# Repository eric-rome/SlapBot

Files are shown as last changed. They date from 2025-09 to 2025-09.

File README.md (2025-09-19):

# SlapBot

SlapBot és un robot físic capaç de jugar al joc de cartes **El Tapete** de manera autònoma.  
Combina visió per computador, control de motors i sensors per reconèixer cartes, prendre decisions i competir contra jugadors humans en temps real.

---

## 🧠 Descripció general

El robot es compon de quatre mòduls principals:

- **Mecanisme de "slap"**: braç que colpeja la taula quan detecta una combinació guanyadora.
- **Llença-cartes**: mecanisme que permet al robot descartar cartes durant la partida.
- **Sistema de visió**: càmera connectada a una Raspberry Pi que reconeix les cartes jugades mitjançant un model de Roboflow.
- **Sensors de detecció de guanyador**: dos sensors d’ultrasons que detecten qui ha picat primer a la taula.

El reconeixement de cartes es fa mitjançant una **API de Roboflow**, integrada al codi de `src/raspberry_pi4`, que processa les imatges captades per la càmera i retorna el valor de la carta al programa principal.  
Inicialment s’havia creat una xarxa neuronal pròpia (`src/neural_network`), però tot i obtenir una bona precisió en entrenament (>0.9), no donava resultats fiables en temps real, per la qual cosa es va optar per utilitzar Roboflow.

---

## 🎥 Vídeo de demostració

Veure vídeo (https://youtu.be/LgzfWQ4xZNc)

---

## ⚙️ Tecnologies utilitzades

**Software**
- Python 3 (Raspberry Pi 4)
- C++ (Arduino Nano)

**API**
- Projecte de Roboflow per a detecció de cartes  
  (vegeu `src/raspberry_pi4/execute_program_and_cite_project_api_roboflow`)

**Hardware**
- Raspberry Pi 4  
- Càmera Eye PlayStation 3  
- Arduino Nano  
- 2 sensors d’ultrasons HC-SR04  
- Motor DC i mini motor DC  
- Controladora TB6612FNG per a motors  
- Altaveu  
- Font d’alimentació de 6 piles (7,2 V a 9 V)

---

## 🧩 Arquitectura

**Esquema de hardware**

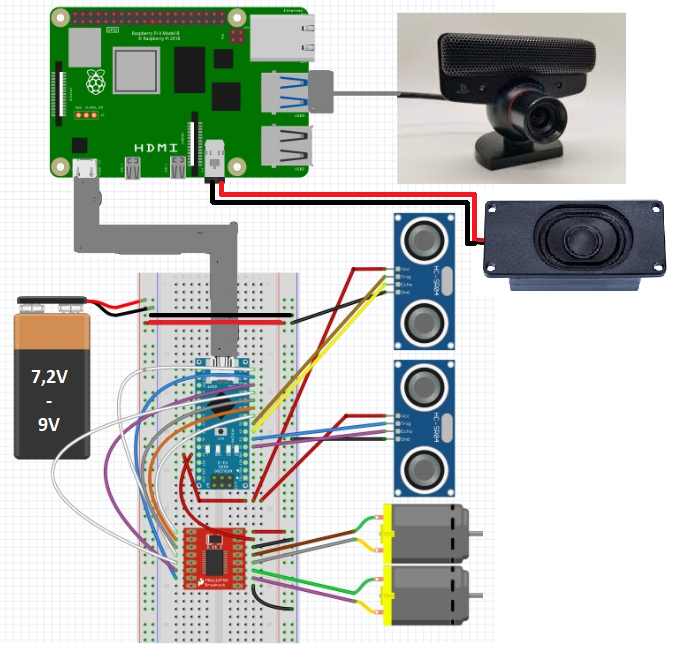
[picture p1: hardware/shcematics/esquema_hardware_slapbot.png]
Esquema de hardware


**Diagrama de software**

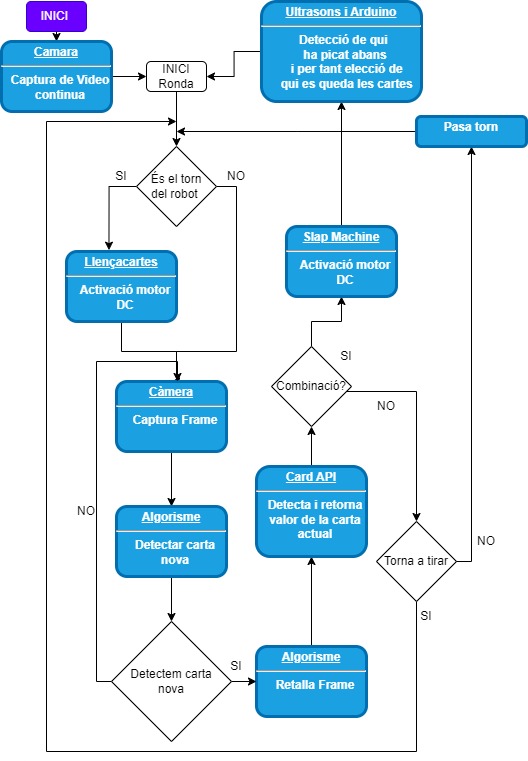
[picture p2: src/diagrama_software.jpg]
Diagrama de software


---

## 📁 Estructura del codi

- **`src/arduino`**  
  Controla els sensors i motors. L’Arduino detecta qui pica primer a la taula (robot o jugadors humans) i envia aquesta informació a la Raspberry Pi. També activa el mecanisme del braç i el llença-cartes quan cal.

- **`src/neural_network`**  
  Conté el codi i el model entrenat per al reconeixement de cartes mitjançant xarxes neuronals. Finalment no es va utilitzar en el sistema final, però s’inclou com a referència i documentació del procés.

- **`src/raspberry_pi4`**  
  Implementa el programa principal, la gestió de torns i la comunicació amb l’Arduino, la càmera i l’API de Roboflow. Inclou instruccions d’execució al fitxer `explicacio.md`.

---

## 🃏 Funcionament del joc

- La partida comença sempre amb el robot per sincronitzar el sistema.  
- Durant el seu torn, el robot llença una carta. Si ha de jugar més d’una, espera a detectar l’última carta llençada abans de continuar.  
- Durant el torn dels jugadors humans, el robot reconeix les cartes jugades amb la càmera i el sistema de visió.  
- Seguint les normes d’**El Tapete**, el robot pica a la taula quan detecta:
  - dues cartes consecutives del mateix valor
  - un “sandvitx” (dues cartes iguals separades per una diferent)
- Els jugadors han de picar entre el sensor i la pila de cartes; si ho fan abans que el robot, se’n porten les cartes.
- Després de cada ronda, si el robot guanya, s’ha de **recarregar el dispensador de cartes manualment** durant una pausa de 20 segons.
- El jugador que acabi amb totes les cartes és el guanyador.

---

## 👥 Autors

- Pol Reyes Martí  
- Eric Rodríguez Merichal 
- Valentí Torrents Vila 
- Guillermo Vivancos Alonso

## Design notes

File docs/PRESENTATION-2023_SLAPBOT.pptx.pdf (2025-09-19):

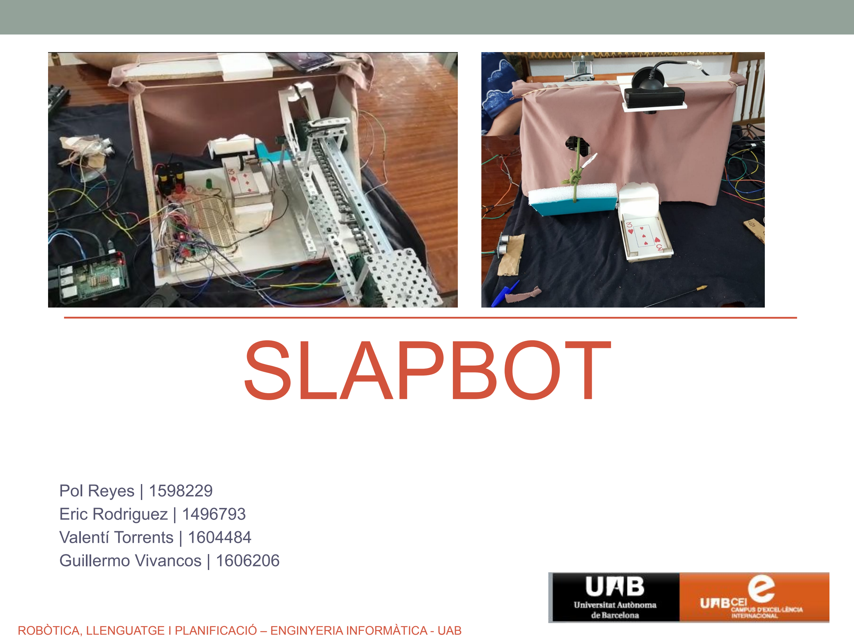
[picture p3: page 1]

# SLAPBOT

Pol Reyes | 1598229
Eric Rodriguez | 1496793
Valentí Torrents | 1604484
Guillermo Vivancos | 1606206

ROBÒTICA, LLENGUATGE I PLANIFICACIÓ – ENGINYERIA INFORMÀTICA - UAB

# 1. Arquitectura hardware i software

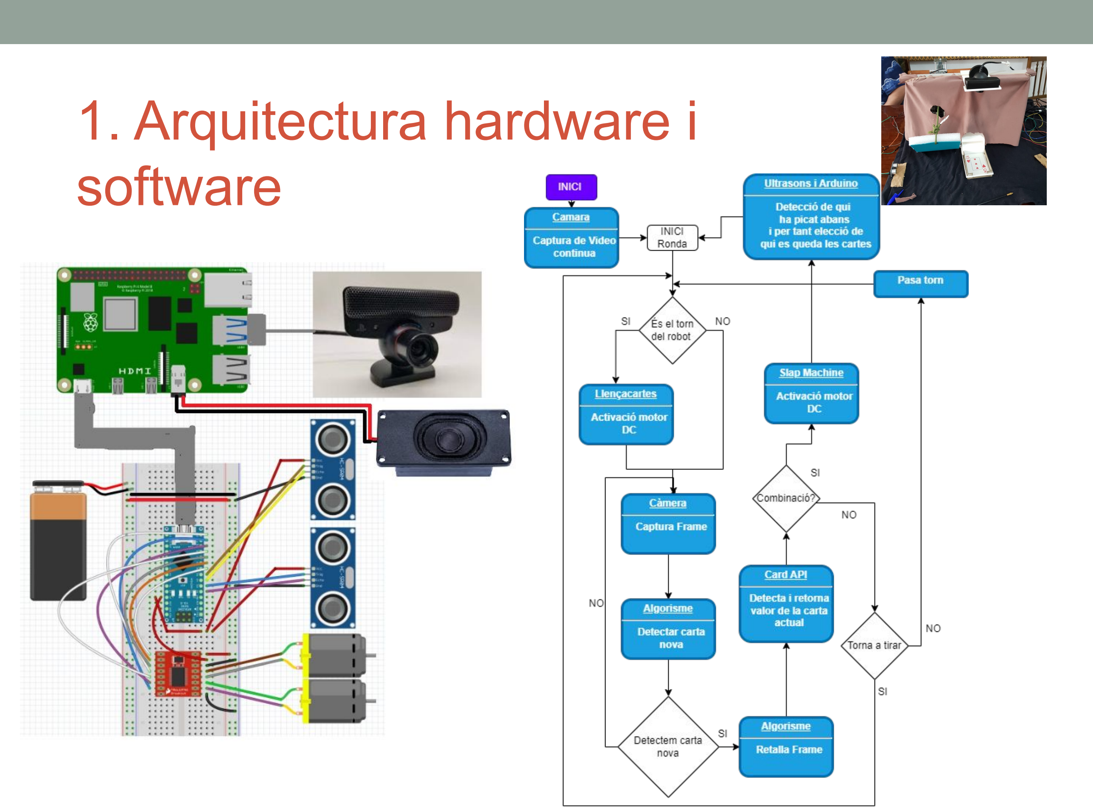
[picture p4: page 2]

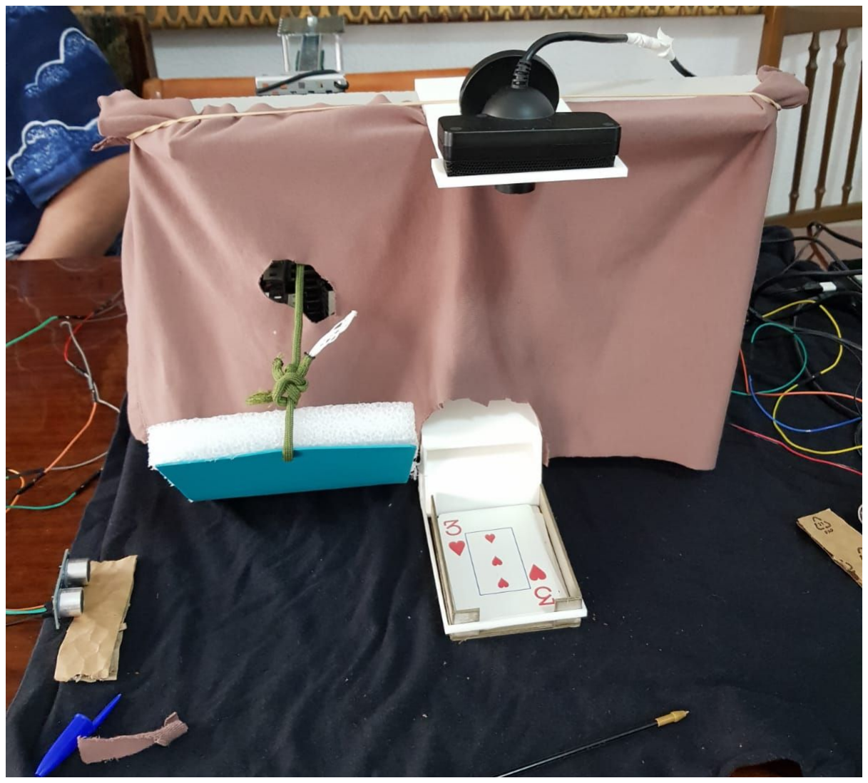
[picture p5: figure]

# 2. Algorísmica

Visió per Computador:
- Xarxa Neuronal per detecció de cartes.
- Retallar frames per evitar el màxim soroll possible.
- Comparació constant de frames.

API:
- Roboflow per a detecció de cartes.

Algorisme:
- Algorisme que permet al robot jugar al “Tapete”.
- Utilitza tots els recursos del robot per jugar.

# FOTOS, VIDEO i Git

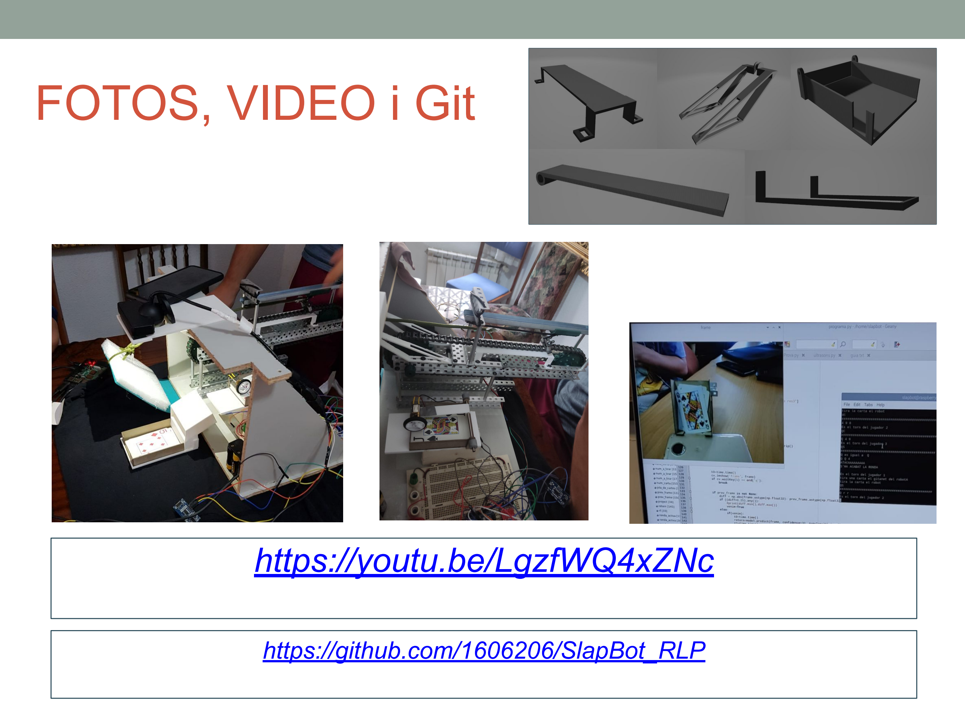
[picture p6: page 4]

## https://youtu.be/LgzfWQ4xZNc

https://github.com/1606206/SlapBot_RLP

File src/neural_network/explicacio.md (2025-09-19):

Tot i aconseguir un accuracy alt de train i un alt accuracy de test amb la BBDD, el passar-ho al programa no aconseguiem que encertes les cartes.
Així doncs, com es reflexa al programa de la raspberry pi s'ha decidit utilitzar l'api de roboflow utilitzant un model ja entrenat.

Així i tot, en aquesta carpeta es pot veure el codi per entrenar el model (.ipynb ja que s'ha utilitzat google colab per entrenar per la falta de recursos que teniem de cpu i gpu), la funció que es cridaria per obtenir la predicció i un exemple de com cridavem la funció utilitzant el model entrenat.

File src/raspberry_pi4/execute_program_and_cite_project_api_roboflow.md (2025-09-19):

# S'utilitza com API de Roboflow per a visió per computador un model ja entrenat.

# Crear un docker a la terminal de la raspberry pi:
curl -fsSL https://get.docker.com -o get-docker.sh
sudo sh get-docker.sh

# Terminal 1 executar les dues comandes següents:
### Comanda 1
sudo docker pull roboflow/inference-server:cpu
### Comanda 2
sudo docker run --net=host roboflow/inference-server:cpu

# Terminal 2 executar les dues comandes següents quan a terminal 1 surti que inference-server està llest per rebre tràfic:
### Comanda 1
python -m venv raspi
### Comanda 2
source raspi/bin/activate

A partir d'aquí executar el programa a la terminal 2 (si no està instal·lat roboflow fer: pip install roboflow al terminal 2):
python3 programa.py

# Citació a l'api de roboflow utilitzada; que al codi programa.py es crida:

@misc{ carddetpokerdeck_dataset,
    title = { carddetpokerdeck Dataset },
    type = { Open Source Dataset },
    author = { h },
    howpublished = { \url{ https://universe.roboflow.com/h-pv33i/carddetpokerdeck } },
    url = { https://universe.roboflow.com/h-pv33i/carddetpokerdeck },
    journal = { Roboflow Universe },
    publisher = { Roboflow },
    year = { 2023 },
    month = { may },
    note = { visited on 2023-06-05 },
}

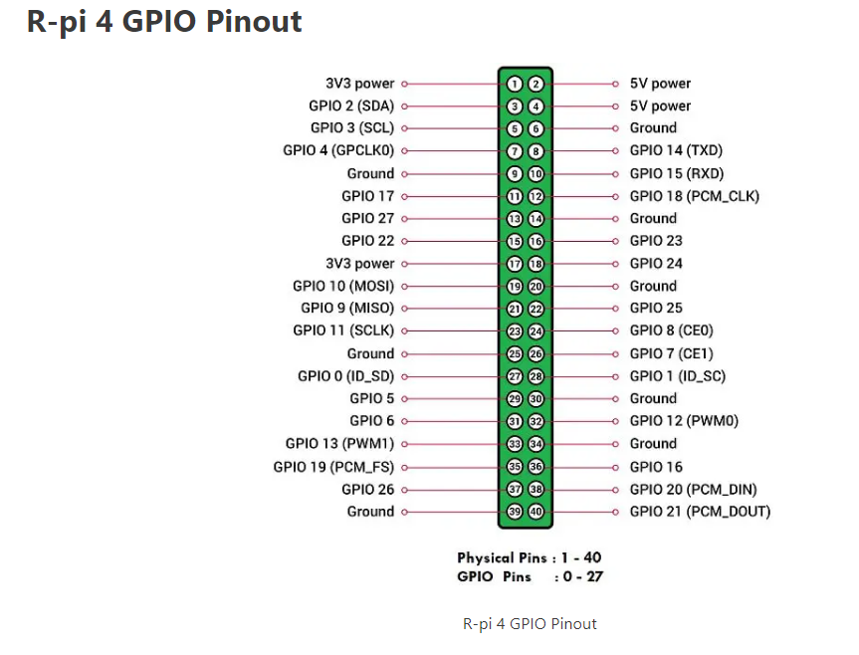
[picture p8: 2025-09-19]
hardware/shcematics/esquema_pi_4.PNG

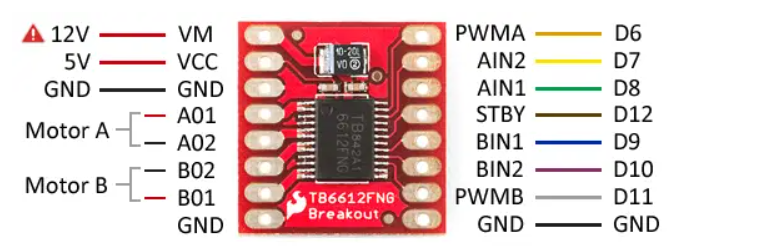
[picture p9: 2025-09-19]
hardware/shcematics/esquema_controladora.png

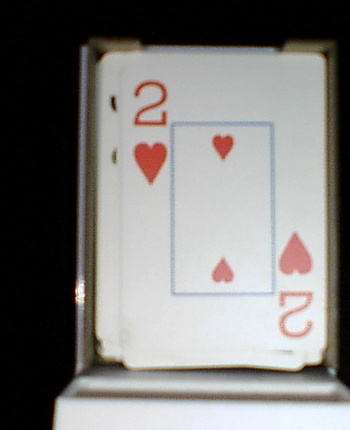
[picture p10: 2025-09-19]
src/neural_network/BBDD/2/2H.jpg

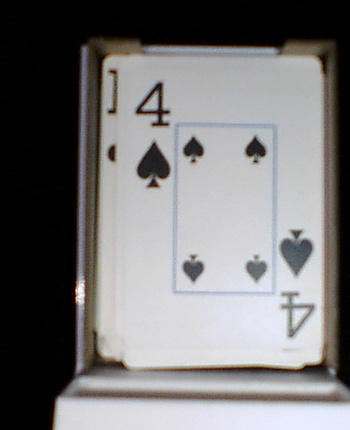
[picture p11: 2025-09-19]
src/neural_network/BBDD/4/4S.jpg

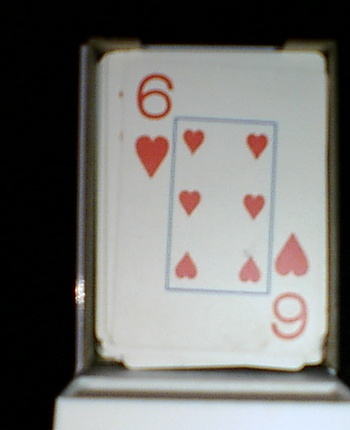
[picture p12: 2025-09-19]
src/neural_network/BBDD/6/6H.jpg

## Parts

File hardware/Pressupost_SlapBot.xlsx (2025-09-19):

Name | Price | Units | Total | URL
Mini motor DC | €3.03 | 1 | €3.03 | https://tienda.bricogeek.com/motores-dc/1606-mini-motor-dc-basico.html
Motor DC | €5.99 | 1 | €5.99 | https://www.vexrobotics.com/motors.html
Sensor ultrasonido | €2.18 | 2 | €4.36 | https://tienda.bricogeek.com/sensores-distancia/741-sensor-de-distancia-por-ultrasonidos-hc-sr04.html
Raspberry Pi 4 | €55.18 | 1 | €55.18 | https://www.raspipc.es/index.php?ver=tienda&accion=verArticulo&idProducto=1750
Arduino nano | €19.97 | 1 | €19.97 | https://tienda.bricogeek.com/arduino/305-arduino-uno.html
Cámara Playstation 3 | €19.00 | 1 | €19.00 | https://www.amazon.es/Sony-C%C3%A1mara-playstation-eye-ps3/dp/B000W3YQ1Y (https://tienda.bricogeek.com/sensores-imagen/1788-camara-hm0360-vga-para-raspberry-pi-pico.html)
Altavoz | €4.35 | 1 | €4.35 | https://tienda.bricogeek.com/varios/938-altavoz-con-caja-3w.html?search_query=speaker&results=3 (https://www.amazon.es/CQRobot-Speaker-Interface-Electronic-Projects/dp/B0822XCPT8?s=computers)
Fuente alimentación rasp | €9.92 | 1 | €9.92 | https://tienda.bricogeek.com/home/1331-fuente-alimentacion-raspberry-pi-4-usb-c-51v-3a.html
Fuente alimentación (petaca pilas) 9V | €1.45 | 1 | €1.45 | https://www.cablepelado.es/portapilas-para-6-pilas-lr6-aa-negro (https://tienda.bricogeek.com/kits-electronica-para-montar/81-kit-fuente-de-alimentacion-dc-5v-33v-para-placa-prototipo.html)
Controladora TB6612FNG | €9.95 | 1 | €9.95 | https://tienda.bricogeek.com/controladores-motores/999-controlador-de-motores-tb6612fng.html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 (https://satkit.com/es/l293d-arduino-shield-driver-control-expansion-para-control-m)
TOTAL |  |  | 133.20€

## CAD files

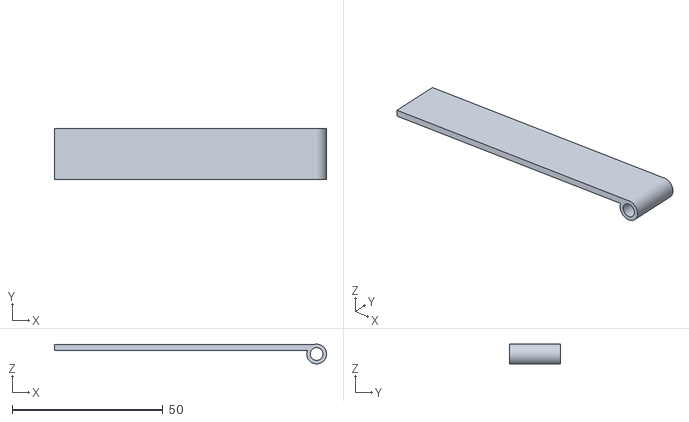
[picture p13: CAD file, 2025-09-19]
hardware/cad/Soporte en varilla para motor DC.stl
90.1 x 17.0 x 6.55

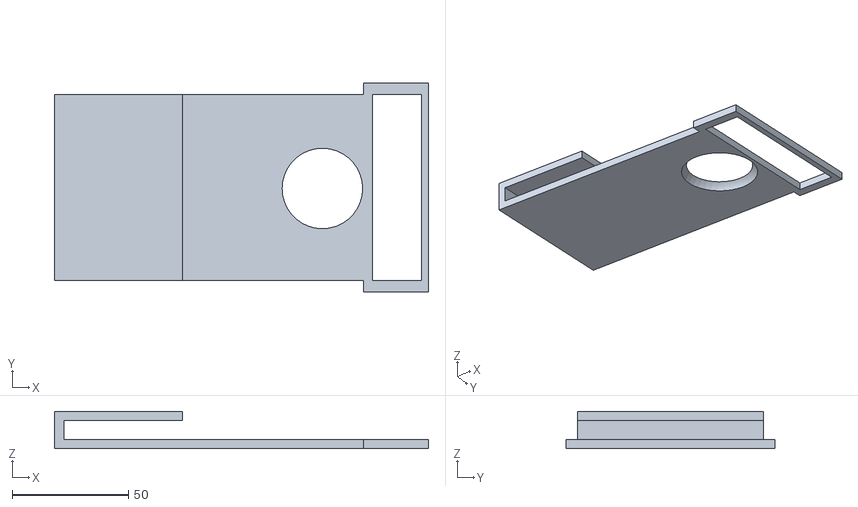
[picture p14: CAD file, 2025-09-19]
hardware/cad/Soporte camara.stl
161.0 x 90.0 x 16.0

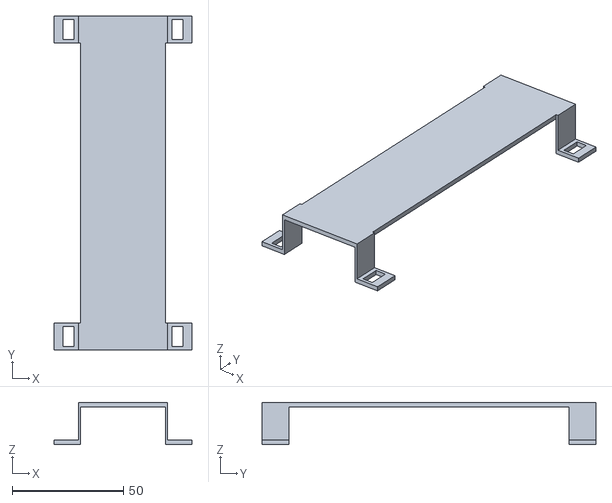
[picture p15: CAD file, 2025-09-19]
hardware/cad/Elevador de cadena.stl
62.0 x 150.0 x 19.0

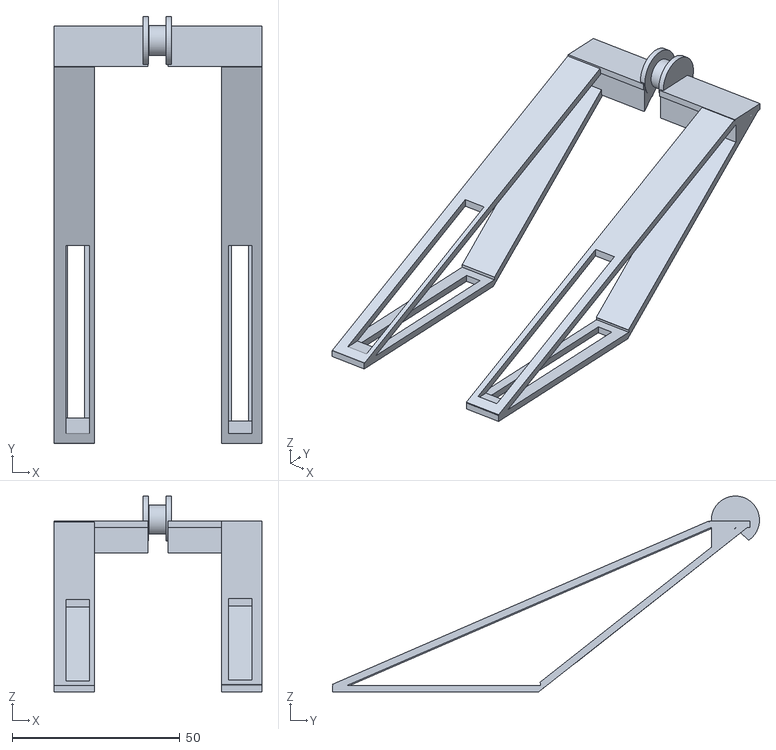
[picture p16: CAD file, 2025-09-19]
hardware/cad/Guia para cuerda.stl
62.0 x 127.4 x 58.4

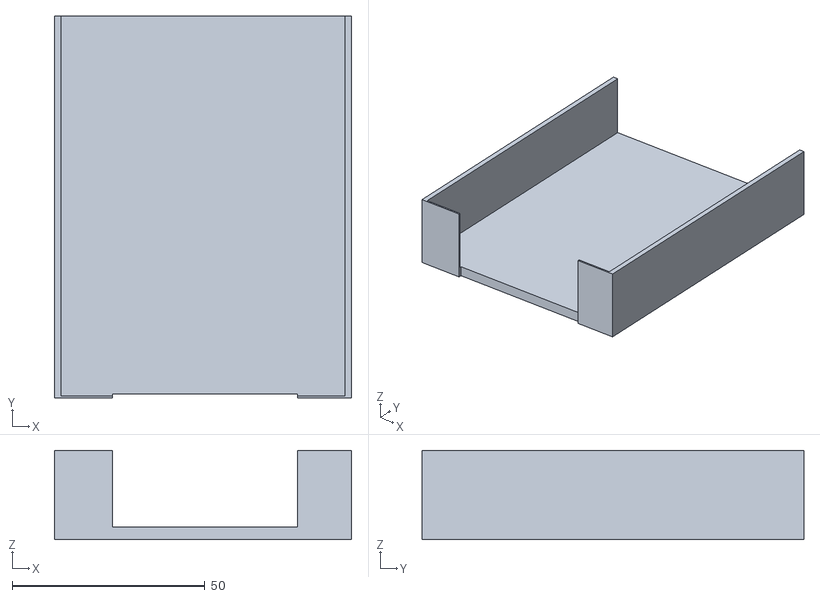
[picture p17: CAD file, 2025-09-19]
hardware/cad/recipiente contenedor de cartas lanzadas (1).stl
77.0 x 99.0 x 23.1

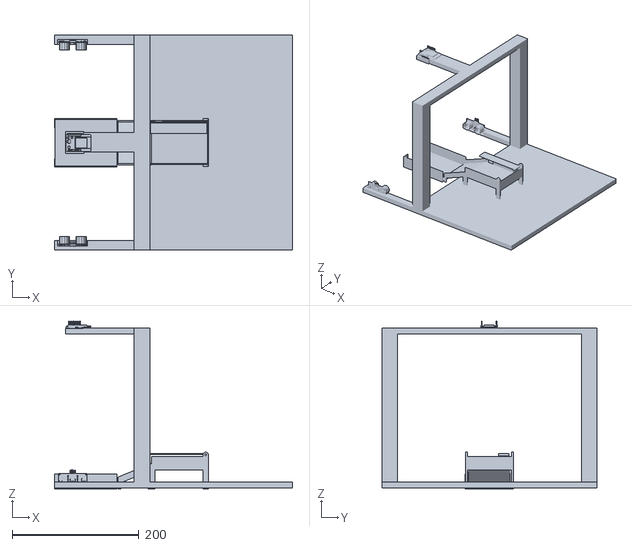
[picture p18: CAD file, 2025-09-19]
hardware/cad/Prototipo maqueta general (Dia 1).stl
376.0 x 340.0 x 264.9

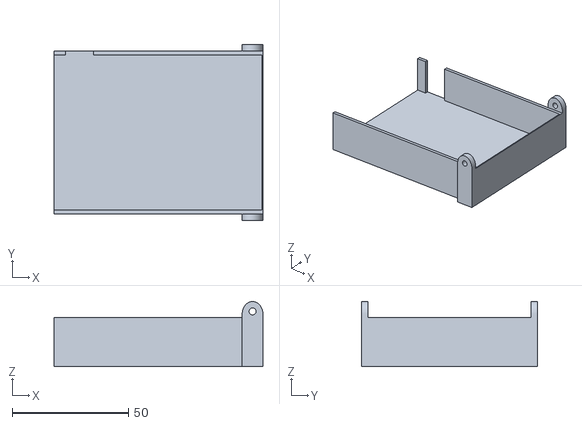
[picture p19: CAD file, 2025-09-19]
hardware/cad/Recipiente dispensador.stl
90.0 x 76.0 x 28.0

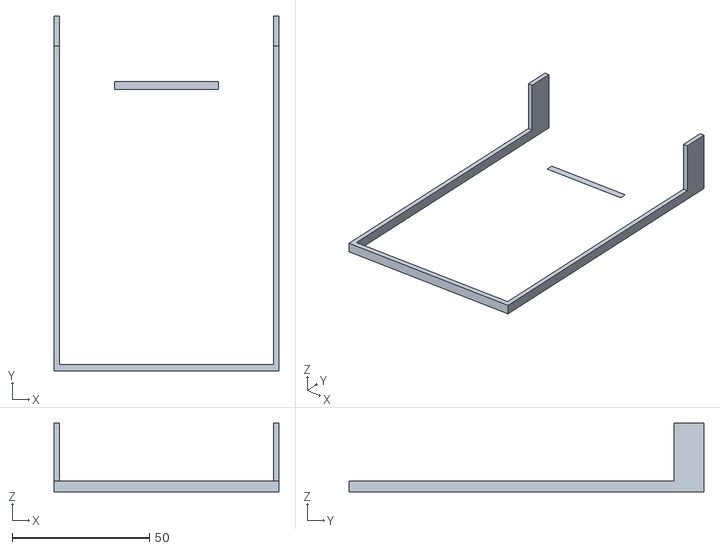
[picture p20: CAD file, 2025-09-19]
hardware/cad/Soporte recipiente Cartas.stl
82.0 x 129.3 x 25.0

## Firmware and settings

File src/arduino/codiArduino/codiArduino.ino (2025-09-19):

const int pinPWMA = 6;
const int pinAIN2 = 7;
const int pinAIN1 = 8;
const int pinBIN1 = 9;
const int pinBIN2 = 10;
const int pinPWMB = 11;
const int pinSTBY = 12;
const int motor = 2;
String receivedData;
const int waitTime = 2000;  //espera entre fases
const int speed = 200;      //velocidad de giro

const int pinMotorA[3] = { pinPWMA, pinAIN2, pinAIN1 };
const int pinMotorB[3] = { pinPWMB, pinBIN1, pinBIN2 };
int inches = 0;

int cm1 = 0;
int cm2 = 0;

enum moveDirection {
  forward,
  backward
};

enum turnDirection {
  clockwise,
  counterClockwise
};

void setup() {
  Serial.begin(9600);
  pinMode(pinAIN2, OUTPUT);
  pinMode(pinAIN1, OUTPUT);
  pinMode(pinPWMA, OUTPUT);
  pinMode(pinBIN1, OUTPUT);
  pinMode(pinBIN2, OUTPUT);
  pinMode(pinPWMB, OUTPUT);
}

long readUltrasonicDistance(int triggerPin, int echoPin) {
  pinMode(triggerPin, OUTPUT);  // Clear the trigger
  digitalWrite(triggerPin, LOW);
  //delayMicroseconds(2);
  // Sets the trigger pin to HIGH state for 10 microseconds
  digitalWrite(triggerPin, HIGH);
  //delayMicroseconds(10);
  digitalWrite(triggerPin, LOW);
  pinMode(echoPin, INPUT);
  // Reads the echo pin, and returns the sound wave travel time in microseconds
  return pulseIn(echoPin, HIGH);
}
void loop() {

  if (Serial.available() > 0) {

    receivedData = "";
    receivedData = Serial.readStringUntil('\n');  // Read the data received from Raspberry Pi as a character
    if (receivedData == "T") {
      tirarCarta();
    }

    if (receivedData == "A") {
      ataca();
    }
  }

  cm2 = 0.01723 * readUltrasonicDistance(5, 4);

  cm1 = 0.01723 * readUltrasonicDistance(3, 2);

  if ((cm1 < 10) && (cm2 > 10)) {
    Serial.write("1");
    delay(10000); // per evitar llegir res durants uns segons un cop s'ha picat la taula (hi ha un delay de 20 segons abans no comenci la següent a la raspi)
  }
  else if ((cm2<10) && (cm1>10)){ 
    Serial.write("2"); 
    delay(10000); // per evitar llegir res durants uns segons un cop s'ha picat la taula (hi ha un delay de 20 segons abans no comenci la següent a la raspi)
  }

}

void ataca() {
  enableMotors();
  moveB(forward, 205);
  delay(1600);

  fullStop();
}

void tirarCarta() {
  enableMotors();
  //tira endavant per llençar carta i endarrera per recollir la següent i que no és llenci també; el segon moviment com a correcció del primer moviment
  moveA(backward, 140);
  delay(200);

  moveA(forward, 150);
  delay(350);

  fullStop();
}

//Funciones que controlan el vehiculo
void moveA(int direction, int speed) {
  if (direction == forward) {
    moveMotorForward(pinMotorA, speed);
  } else {
    moveMotorBackward(pinMotorA, speed);
  }
}

void moveB(int direction, int speed) {
  if (direction == forward) {
    moveMotorForward(pinMotorB, speed);
  } else {
    moveMotorBackward(pinMotorB, speed);
  }
}

void turn(int direction, int speed) {
  if (direction == forward) {
    moveMotorForward(pinMotorA, speed);
    moveMotorBackward(pinMotorB, speed);
  } else {
    moveMotorBackward(pinMotorA, speed);
    moveMotorForward(pinMotorB, speed);
  }
}

void fullStop() {
  disableMotors();
  stopMotor(pinMotorA);
  stopMotor(pinMotorB);
}

//Funciones que controlan los motores
void moveMotorForward(const int pinMotor[3], int speed) {
  digitalWrite(pinMotor[1], HIGH);
  digitalWrite(pinMotor[2], LOW);

  analogWrite(pinMotor[0], speed);
}

void moveMotorBackward(const int pinMotor[3], int speed) {
  digitalWrite(pinMotor[1], LOW);
  digitalWrite(pinMotor[2], HIGH);

  analogWrite(pinMotor[0], speed);
}

void stopMotor(const int pinMotor[3]) {
  digitalWrite(pinMotor[1], LOW);
  digitalWrite(pinMotor[2], LOW);

  analogWrite(pinMotor[0], 0);
}

void enableMotors() {
  digitalWrite(pinSTBY, HIGH);
}

void disableMotors() {
  digitalWrite(pinSTBY, LOW);
}

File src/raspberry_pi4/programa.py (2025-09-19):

import random
import glob
import time as time
import numpy as np
import roboflow as Roboflow
import matplotlib.pyplot as plt
import matplotlib.image as mpimg
import cv2
import serial
import pyCardDeck
from playsound import playsound


#connectar la raspberry pi i l'arduino
ser = serial.Serial('/dev/ttyUSB0', 9600, timeout=1)
ser.reset_input_buffer()

#carregar API roboflow
rf = Roboflow.Roboflow(api_key="7amu8FnEjKxcYScY98i3")
project = rf.workspace("h-pv33i").project("carddetpokerdeck")
model = project.version(1, local="http://localhost:9001/").model

#obrir la càmera
cap = cv2.VideoCapture(0)
if not cap.isOpened():
    print("Cannot open camera")
    exit()
time.sleep(2)
   
N_JUGADORS = 3
POSSIBLES_NUMS = ["1", "2", "3","4","5","6","7","8","9","10","J","Q","K"]
POSSIBLES_PALS = ["picas","cors","trebols","diamants"]
cartesEspecials =	{
    'J': 1,
    'Q': 2,
    'K': 3,
    'A': 4
}

def pasarTorn(torn):
    torn =torn + 1
    if(torn == N_JUGADORS):
        torn = 0
    return torn
    
def trobarCombinacio(pila_de_cartes):
    trobat = False
    
    if len(pila_de_cartes[0].split()[0]) == 3:
        num0='10'
    else:
        num0 = pila_de_cartes[0].split()[0][0]
        
    if len(pila_de_cartes[1].split()[0]) == 3:
        num1='10'
    else:
        num1 = pila_de_cartes[1].split()[0][0]
        
    if len(pila_de_cartes[2].split()[0]) == 3:
        num2='10'
    else:
        num2 = pila_de_cartes[2].split()[0][0]
        
        
        
    if(num0==num1):
        trobat = True
        print("DOS IGUAAALS")
        
    if(num0==num2):
        trobat = True
        print("SANDWIIICH")
    return trobat


# When everything done, release the capture

prev_frame=None
ret, frame = cap.read()
while(True):
    data=0
    pila_de_cartes=["re de res1", "re de res2", "re de res3"]
    torn = 0
    carta_especial = False
    num_a_tirar = 1
    nova_carta = "re de res1"
    ronda_activa = True
    data=0
    ser.reset_input_buffer()
    while ronda_activa:
        print("Es el torn del jugador", torn+1)
        if(torn==0):
            time.sleep(2)
            ser.write(b"T\n")
            print("tira la carta el robot")
            if ser.inWaiting()>0:
                ronda_activa = False
                break
        if ronda_activa!=False:
            venim=False
            while(nova_carta==pila_de_cartes[0] and ronda_activa!=False):
                ret, frame = cap.read()
                t0=time.time()
                cv2.imshow('frame', frame[0:430, 100:450])
                if cv2.waitKey(1) == ord('q'):
                    break
                if prev_frame is not None:
                    diff = np.abs(frame.astype(np.float32)- prev_frame.astype(np.float32))/255   
                    if ((diff>0.25).any()):
                        venim=True
                    else:
                        if(venim):
                            t0=time.time()
                            retorn=model.predict(frame[0:430, 100:450], confidence=30, overlap=30).json()
                            t1=time.time()
                            if(len(retorn['predictions'])>0):
                                nova_carta = retorn["predictions"][0]['class']
                        venim=False      
                prev_frame=frame
                if ser.inWaiting()>0:
                    ronda_activa = False
                    break                  
        if ronda_activa!=False:
            all_words = nova_carta.split()
            num_carta = all_words[0]
            print(nova_carta)
            print("#################################################")
            num_a_tirar = num_a_tirar - 1

            pila_de_cartes.insert(0, nova_carta)
            pila_de_cartes.pop(3)
            combinacio = trobarCombinacio(pila_de_cartes)
            if(combinacio): 
                ser.write(b"A\n")
                print("ATACAAAAAAAAA")
                playsound('audios/audio1.mp3')
                ronda_activa = False
            else:
                if(num_carta[0] in cartesEspecials):
                    print("es unacarta especial")
                    torn = pasarTorn(torn)
                    carta_especial = True
                    num_a_tirar = cartesEspecials[num_carta[0]]
                else:
                    if(num_a_tirar==0):
                        if(carta_especial==True):
                            
                            carta_especial = False
                            ronda_activa = False
                            printatorn = torn
                            if(printatorn==0):
                                printatorn=1
                            print("Se les emporta el jugador ", printatorn)
                        else:
                            torn = pasarTorn(torn)
                            carta_especial = False
                    else:
                        if(carta_especial == False):
                            torn = pasarTorn(torn)
    while ser.inWaiting()==0:
        pass
    data=ser.readline().decode('utf-8').rstrip()
    if(data==1):
        print("Ha guanyat el robot")
    elif(data==2):
        print("Han guanyat els humans")  
    print("S'HA ACABAT LA RONDA")
    time.sleep(20) #temps per recarregar les cartes el robot en cas que hagi guanyat
    
cap.release()
cv2.destroyAllWindows()
